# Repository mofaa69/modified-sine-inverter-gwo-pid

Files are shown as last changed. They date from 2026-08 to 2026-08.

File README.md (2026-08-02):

# Metasezgisel Algoritma Tabanlı Modifiye Sinüs Evirici (Inverter) Tasarımı

Bu proje, **TÜBİTAK 2209-A Üniversite Öğrencileri Araştırma Projeleri Destekleme Programı** (Proje No: 1919B012454606) kapsamında **Karadeniz Teknik Üniversitesi Elektrik-Elektronik Mühendisliği Bölümü**'nde tamamlanmış lisans bitirme çalışmasıdır.

---

## 📌 Proje Özeti
Bu çalışmada, 24V DC giriş gerilimini 12V-18V RMS 50Hz AC çıkış gerilimine dönüştüren, 180W maksimum güce sahip kapalı çevrim bir modifiye sinüs evirici sistemi tasarlanmış ve prototipi üretilmiştir. Sistemin güç hatları pcb üzerinde yapılmamış olup 1.5mm çok damarlı kablolar ile hibrit bir şekilde yapılmıştır.PCB üzerinde mikrokontrolcü yuvası tasarımı Attiny85 için yapılmıştır ancak kolaylıkla arduino mikrokontrolcülerle beraber de kullanılabilir.

Çıkış geriliminin kararlılığını sağlamak için Arduino tabanlı bir **PID denetleyici** kurgulanmış; PID kontrolörün Kp ve Ki parametreleri metasezgisel bir sürü zekası algoritması olan **Gri Kurt Optimizasyonu (GWO)** ile optimize edilmiştir.

---

## 🛠️ Donanım & Sistem Mimarisi

* **Güç Katı & Topoloji:** 24V DC beslemeli, 4 adet **IRLZ44N MOSFET** ile kurgulanmış H-Köprüsü (H-Bridge) topolojisi.
* **Sürücü Katı & Bootstrap:** High-side MOSFET tetikleme problemini çözmek amacıyla **IR2110** sürücü entegreleri ve 47µF/25V kondansatör + UF4007 hızlı diyottan oluşan **Bootstrap (Yüzer Kaynak)** mimarisi.
* **Mikrodenetleyici:** Arduino Uno R3 (ATmega328P) — Donanımsal Timer kesmeleri (Timer1 ISR) kullanılarak 50Hz Hassas PWM sinyali üretimi.
* **Geri Besleme & Sensör:** Tam dalga diyot köprüsü (UF4007), $22k\Omega / 4.7k\Omega$ gerilim bölücü ve 10µF filtre kapasitöründen oluşan feedback devresi.
* **Kullanıcı Arayüzü:** I2C modüllü 16x2 LCD ekran ve potansiyometre ile 12V–18V arası anlık referans gerilimi ayarlama.
3d devre
---

## 📊 Simülasyon ve Optimizasyon (GWO)

* **MATLAB / Simulink:** H-Köprüsü güç katı, yük değişimleri ve batarya voltaj düşümü senaryoları altında kapalı çevrim olarak simüle edilmiştir.
* **Gri Kurt Optimizasyonu (GWO):** Simulink modeliyle entegre çalışan MATLAB algoritması sayesinde minimum hata kriterine göre en ideal kontrolör parametreleri tespit edilmiştir.

---

## 📁 Depo İçeriği

* **`/pcb`**: Şematik çizimler, PCB layout ve 3D kart modelleri.
* **`/simülasyon`**: GWO optimizasyon `.m` kodları ve kapalı çevrim Simulink (`.slx`) modeli.
* **`/yazılım`**: Timer kesmeli, I2C ekran destekli ve anlık PI kontrol hesaplamalı C++ / Arduino kodları.
* **`/proje raporu`**: KTÜ Bitirme Projesi nihai raporu (PDF).

---

## 🔬 Laboratuvar & Deneysel Sonuçlar
Fiziksel olarak üretilen baskı devre (PCB) üzerinde yapılan testlerde, 8.2Ω / 4A yük altında 12.00V ve 18.03V True RMS çıkış değerleri elde edilmiş, simülasyon sonuçları ile deneysel verilerin tam uyum sağladığı doğrulanmıştır.

---

## 🛠️ Kullanılan Teknolojiler
`KiCad` | `MATLAB / Simulink` | `Arduino IDE` | `C/C++` | `GWO Algorithm` | `PID Control`

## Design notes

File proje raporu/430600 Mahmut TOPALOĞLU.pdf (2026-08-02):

T.C.

## KARADENİZ TEKNİK ÜNİVERSİTESİ Mühendislik Fakültesi

### Elektrik-ElektronikMühendisliği Bölümü

# Metasezgisel Algoritma Tabanlı Modifiye Sinüs Evirici

### (Bitirme projesi)

### 430600 Mahmut TOPALOĞLU

## Dr. Öğr. Üyesi YAHYA DANAYİYEN

### Mayıs 2026 TRABZON

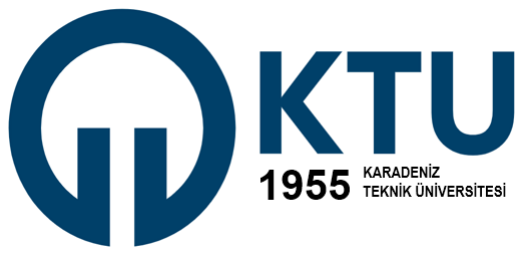
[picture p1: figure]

T.C.

## KARADENİZ TEKNİK ÜNİVERSİTESİ Mühendislik Fakültesi

### Elektrik-ElektronikMühendisliği Bölümü

# Metasezgisel Algoritma Tabanlı Modifiye Sinüs Evirici

### (Bitirme Projesi)

### 430600 Mahmut TOPALOĞLU

## Dr. Öğr. Üyesi YAHYA DANAYİYEN

### Mayıs 2026 TRABZON

i

LİSANS BİTİRME PROJESİ ONAY FORMU

Mahmut TOPALOĞLU tarafından Dr. Öğr. Üyesi Yahya DANAYİYEN yönetiminde

hazırlanan “Metasezgisel Algoritma Tabanlı Modifiye Sinüs Evirici” başlıklı lisans

bitirme projesi tarafımızdan incelenmiş, kapsamı ve niteliği açısından bir Lisans Bitirme

Projesi olarak kabul edilmiştir.

Danışman | : Dr. Öğr. Üyesi Yahya DANAYİYEN
Jüri Üyesi 1 | : Prof. Dr. H. İbrahim OKUMUŞ
Jüri Üyesi 2 | : Dr. Öğr. Üyesi Hakan KAHVECİ
Bölüm Başkanı | : Prof. Dr. AYTEN ATASOY

ii

### ÖNSÖZ

Bitirme çalışmam boyunca hiçbir zaman desteklerini esirgemeyen, bilgi ve tecrübeleriyle bana yol gösteren danışman hocam Sayın Dr. Öğr. Üyesi Yahya

DANAYİYEN başta olmak üzere tüm değerli hocalarıma içten teşekkürlerimi sunarım.

Projeyi hayata geçirirken sundukları imkân ve olanaklar için Karadeniz Teknik Üniversitesi Elektrik-Elektronik Mühendisliği Bölüm Başkanlığı’na şükranlarımı

iletirim. Ayrıca, bu tez çalışması TÜBİTAK Bilim İnsanı Destek Programları

Başkanlığı (BİDEB) tarafından yürütülen 2209-A Üniversite Öğrencileri Araştırma

Projeleri Destekleme Programı kapsamında, 1919B012454606 başvuru numaralı ve

"Metasezgisel Algoritma Tabanlı Modifiye Sinüs Kesintisiz Güç Kaynağı" başlıklı

proje ile desteklenmiştir. Sağladıkları desteklerden dolayı Türkiye Bilimsel ve Teknolojik Araştırma Kurumu’na (TÜBİTAK) teşekkür ederim.

Eğitim ve öğrenim hayatım boyunca her zaman yanımda olan, sevgileri ve destekleriyle

beni daima güçlendiren değerli aileme ise sonsuz şükranlarımı sunarım.

Mahmut Topaloğlu

2026 Trabzon

iii

İÇİNDEKİLER

iv

### 1.8.9. İş Paketi 9 | 11

### 1.8.10. İş Paketi 10 | 11

### 2.TEORİK ALTYAPI | 12

### 2.1. Genel Bilgiler | 12

### 2.1.1 Evirici Devresi Tasarımı | 12

### 2.1.2. PID Kontrolcü Tasarımı | 13

### 2.4. Güç Elektroniği Elemanları | 20

### 3. TASARIM | 19

### 3.1. Genel Bilgiler | 19

### 3.2. Boyutlandırmalar | 19

### 3.3. Sistem Bileşenleri ve Seçimleri.. | 20

### 3.3.1. Batarya | 20

### 3.3.2. MOSFET | 21

### 3.3.3. MOSFET Sürücü Entegresi | 22

### 3.3.4. Bootstrap Devresi.. | 22

### 3.3.5. Arduino Uno R3 | 23

### 3.3.6. Manuel Anahtar | 24

### 3.3.7. Gerilim Sensörü | 24

### 3.3.8. LCD Ekran | 26

### 3.3.9. I2C Modülü | 26

### 3.4. Uygulanan Yöntemler | 27

### 3.5. Yazılımlar | 27

### 3.6. Malzeme Listesi ve Ekonomik Analiz | 27

### 3.7. Hukuki Boyut | 28

v

vi

ÖZET

Bu projede, genel kullanım amaçlı metasezgisel algoritma tabanlı bir modifiye

sinüs evirici tasarımı yapılacaktır. Evirici çıkış gerilimi PID denetleyici ile kontrol

edilecek olup, PID denetleyici parametreleri de metasezgisel algoritmalar ile

belirlenecektir. Bu projede, çıkış gerilimini tasarlayacağımız PID denetleyici ile anlık

olarak kontrol ederek sistemin verimini ve kalitesini artırmayı amaçlıyoruz.

Projede tasarlanacak evirici devresi ve mikrodenetleyici tarafından oluşturulan

PWM sinyalleri aracılığıyla 12V-18V 50Hz modifiye sinüs gerilime çevrilip çıkışa

verilecektir. Bu çevrim işlemi de tasarlayacağımız PID kontrolcü ile denetlenerek çıkış

geriliminin kalitesi artırılacaktır. Cihazın maksimum çıkış gücü 180W olacaktır.

Çıkıştaki gerilimin efektif değeri bir ekran vasıtası ile gözlemlenebilecektir Yük olarak

8.2 ohm ve 4A değerindeki direnç yükü kullanılacaktır.

vii

SEMBOLLER VE KISALTMALAR

KGK: Kesintisiz Güç Kaynağı

PWM: Pulse Width Modulation

PID: Proportional Integral Derivative

ADC: Analog - Digital Converter

ms: Milisaniye

GWO: Grey Wolf Optimization

V: Volt

A: Amper

W: Watt

R: Direnç

C: Kapasite

L: Endüktans

DA: Doğru Akım

AA: Alternatif Akım

Hz: Hertz

USB: Universal Serial Bus

Wh: Watt Saat

Ah: Amper Saat

D: Duty Cycle (Görev Döngüsü)

GND: Ground

LCD: Liquid Crystal Display

I2C: Inter-Integrated Circuit

IEEE: Institute of Electrical and Electronics Engineers

IEC: International Electrotechnical Commission

ISO: International Standards Organization

viii

ŞEKİLLER DİZİNİ

ix

ÇİZELGELER DİZİNİ

### 1. GİRİŞ

### 1.1. Genel Bilgiler

Evirici Nedir, Kullanım Alanları ve Önemi

Evirici, teknik literatürde “Inverter” olarak adlandırılan ve Doğru Akımı (DC)

Alternatif Akıma (AC) dönüştüren bir güç elektroniği devresidir. Elektrik şebekesinin

bulunmadığı veya kesildiği durumlarda; bataryalar, güneş panelleri veya diğer DC

kaynaklardan elde edilen enerji, evlerde ve endüstriyel tesislerde kullanılan şebeke

formatına bu birimler aracılığıyla dönüştürülür. Kesintisiz Güç Kaynaklarının (KGK)

temel işlevi olan enerji yedekleme süreci, bataryadaki gücün kullanılabilir bir forma

sokulmasını sağlayan evirici modülünün performansına doğrudan bağlıdır.

Teknolojik cihazların hassasiyeti ve yenilenebilir enerji kaynaklarına olan yönelim

dünya genelinde arttıkça, verimli enerji dönüşümü sağlayan evirici sistemlerinin önemi

de artış göstermektedir. Kararlı bir alternatif akım arzı, sistem güvenliği açısından

kritik bir parametredir. Bu doğrultuda evirici sistemlerinin önemi ve kullanım alanları

şu şekilde özetlenebilir:

- Enerji Kalitesi ve Cihaz Güvenliği: Eviriciler (özellikle tam sinüs dalga

üreten modeller), şebeke kalitesinde temiz ve dalgalanmasız bir alternatif akım

üreterek hassas elektronik donanımların elektriksel gürültüden veya uygunsuz

dalga formlarından zarar görmesini engeller. Bu durum, cihazların kullanım

ömrünü uzatırken yüksek bakım maliyetlerinin önüne geçer.

- Yenilenebilir Enerji Entegrasyonu: Güneş enerjisi ve rüzgar türbinleri gibi

kaynaklardan elde edilen enerjinin günlük kullanıma uygun hale getirilmesi

veya şebekeye geri basılması ancak yüksek verimli eviriciler aracılığıyla

mümkündür.

- Şebekeden Bağımsız (Off-Grid) Sistemler: Elektrik şebekesinin ulaşamadığı

kırsal bölgelerde, karavanlarda veya acil durum sahalarında kurulan bağımsız

sistemlerde eviriciler, depolanmış enerjiyi kullanılabilir hale getirerek yaşam ve

çalışma sürekliliğini sağlar.

Tüm bu etkenler ve güç elektroniği prensipleri göz önüne alındığında; bu çalışma

kapsamında doğru akımı düşük kayıp ve yüksek verimle alternatif akıma çeviren,

kaliteli ve temiz enerji ihtiyacını karşılayacak bir modifiye sinüs evirici tasarımı

gerçekleştirilmesi hedeflenmiştir.

### 1.2. Literatür Araştırması

Tasarlanacak olan proje için gerekli literatür arştırması yapılmıştır. Proje ile alakalı

olan bazı kaynaklar ve içerikleri aşağıda belirtilmiştir.

BP, yıllık Dünya Enerjisi 2022 İstatistiksel Raporunda, küresel birincil enerji

talebinin 2021 yılında yüzde 5,8 arttığını ve 2019’daki pandemi öncesi seviyelerini

yüzde 1,3 oranında aştığını belirtmiştir. BP’nin yakından izlenen enerji raporuna

göre, 2021’de birincil enerji, tarihin en büyük miktarıyla büyümüştür. [1]. Büyüyen

bu enerji ihtiyacının sağlanabilmesi için çoğunlukla fosil yakıtlar kullanılmıştır [2].

Fosil yakıtların doğaya verdikleri zarar bilindiğinden ve enerjiyi doğaya daha fazla

zarar verilmeden elde etmek istenildiğinden, bu kaliteli ve temiz enerji ihtiyacını

karşılamak için geliştirilen çözümlerden biri güç kaynaklarıdır. Güç kaynakları

mekanik ve elektrikli olarak ikiye ayrılır. Mekanik güç kaynakları gazla benzinle

veya dizel çalışan jeneratörlere denir, bunun yanında rüzgâr yoluyla elde edilen

elektrik enerjisi de bu gruba girer. Elektrikli güç kaynakları ise KGK (Kesintisiz Güç

Kaynakları) yani eviriciler ve güneş enerjisi sistemleridir. Burada bahsedilen kaliteli

enerji ihtiyacını karşılamak için verimliliği daha yüksek olması sebebiyle [3] bir

modifiye sinüs evirici üzerinde durulacaktır.

A. H. Eltom ve A. Demirbas tarafından 2009 yılında Miami, Florida’da

gerçekleştirilen “IEEE International Conference on Electric Machines and Drives

(IEMDC)” konferansında sunmuş oldukları çalışmanın konferans bildirisinde,

naylon endüstrisindeki motor sistemlerinin enerji verimliliği, PWM ve kare dalga

inverterler kullanılarak karşılaştırılmıştır. Deneysel veriler göstermiştir ki, PWM

inverterlerin motor akım harmonikleri %15 oranında azalmış ve motor verimliliği

%10’a kadar artmıştır. Ayrıca, kare dalga inverterlerin daha yüksek harmonik

distorsiyona neden olduğu ve enerji kayıplarını artırdığı tespit edilmiştir. Çalışma,

PWM inverterlerin enerji tasarrufu ve motor performansı açısından daha avantajlı

olduğunu ortaya koymuştur.[4]

S. Nur Dirim 2010 yılında adaptif kontrol sistemleri ve uygulamaları hakkında bir

derleme makale yayımlamıştır. Çalışmasında adaptif kontrol sistemini PID

kontrolcü sistemi ile kıyaslamıştır. Adaptif kontrol sistemi, kontrol ettiği prosesteki

değişimlere göre kendi kontrol parametrelerini otomatik olarak değiştiren sistem olarak tanımlanır ve prosesin çalışma koşullarının ya da çevre koşullarının

değişmesi | sonucunda | kontrol | sistemindeki | ayarlarının | sürekli | olarak

değiştirilmesiyle gerçekleşir [5].

Model Öngörülü Kontrol Sistemi: Model Öngörülü Kontrol, sürecinin gelecekteki

çıkışları hakkında tahminlerde bulunmak için sisteme ait bir modele ihtiyaç duyan bir geri-beslemeli kontrol algoritmasıdır. Öngörü, öngörü ufku olarak adlandırılan

sonlu bir zaman aralığında sisteme ait bir modele dayalı olarak gerçekleştirilir.

Optimizasyon probleminin çözümü, optimal dizinin ilk elemanının sisteme enjekte

edildiği kontrol vektörünü oluşturur. Güncellenen sistem bilgisi kullanılarak bir

sonraki zaman aralığı için problem tekrar çözülür.[6]

Bulanık Mantık (Fuzzy Logic): Bulanık mantık kontrol sistemlerinde belirsiz ve

kesin olmayan bilgilerin temsil edilmesine olanak tanır. Geleneksel kontrol

tekniklerinden farklı olarak, kesin matematiksel modeller yerine dilsel değişkenler,

bulanık kümeler ve dilsel kurallar kullanır. Bu sayede kontrol sistemi, insan benzeri

bir mantıkla karar verebilir ve değişen koşullara uyum sağlayabilir. Fuzzy PID

kontrolcü, üç ana bileşenden oluşur: Bulanık Mantık Kontrolörü (FLC), PID

kontrolcü ve bu iki çıktıyı birleştiren bir harmanlama mekanizması.[7]

Dayanıklı Kontrol Sistemi (Robust Control): Dayanıklı kontrol, bilinmeyen parazit

sinyallerine, belirsiz dinamiklere sahip ve kesin olarak bilinen veya bilinmeyen

parametrelere sahip sistemler için tasarlanan sabit bir kontrolörün sistemdeki tüm

etkilere rağmen sistemi dayanıklı ve kararlı yapmasını sağlamak için kullanılır.[8]

PID Kontrol Sistemi: PID kontrolörü ilk olarak 1939'da piyasaya sürülmüştür ve

günümüze kadar süreç kontrolünde en yaygın kullanılan kontrol mekanizması

olmuştur. 1989 yılında Japonya'da yapılan bir araştırma, süreç endüstrilerinde

kullanılan kontrolörlerin %90'ından [9] fazlasının PID kontrolörleri veya PID

kontrolörlerinin gelişmiş versiyonları olduğunu göstermiştir. PID açılım olarak Proportional-Integral-Derivative yani Oransal-İntegral-Türevsel kontrol anlamına

gelir ve sistemin istenen bir hedef değere (setpoint) ulaşmasını sağlamak için hata

sinyalini (mevcut değer ile hedef değer arasındaki fark) düzenlemek amacıyla üç

bileşeni kullanır. Bunlar Kp, Ki ve Kd parametreleridir.

### 1.3. Özgünlük

Geliştirecek eviricinin en önemli bölümü kullanılacak kontrol tekniğidir. Kontrol

teknikleri temelde 2 ana başlıkta değerlendirilir;

- Açık döngü kontrol sistemleri
- Kapalı döngü kontrol sistemleri

Açık döngü kontrol sistemlerinde sistemin girişine istenilen ayarlamalar yapılır ve

sistem çıkışı denetlenmez. Kapalı döngü kontrol sistemlerinde iste sistem çıkışı belirli

sensörler yardımı ile denetlenir ve giriş verisi, çıkış verisine göre tekrar düzenlenerek

yeni bir çıkış oluşturulur.

Tasarlanacak olan proje kapalı döngü bir sistem olacaktır ve çıkış geriliminin

oluşturulmasında bir PID kontrolcü kullanılacaktır. PID kontrolcünün kontrol

parametreleri ise metasezgisel bir algoritma olan “Gri Kurt Optimizasyon Algoritması”

ile hesaplanacaktır. Sistemde parametrelerin belirlenebilmesi için gri kurt algoritması

kullanılacaktır. Kullanım sebepler ise gri kurt optimizasyon (GWO) algoritması, basit

uygulanabilirliği, hızlı yakınsaması ve üstün yakınsama sonuçları gibi birkaç önemli

avantaja sahiptir. Bu özellikleri, algoritmanın optimizasyon sorunlarını çözmede farklı

alanlarda etkili bir şekilde kullanılmasını sağlamaktadır [10].

Literatür incelendiğinde, tasarlanan evirici çıkışlarında harmoniklerin doğrusal

olmayan yükte %5’ten büyük olduğu, tasarlanan kontrol algoritmalarının karmaşık ve

yüksek işlem yükü gerektirdiği, anahtarlama kayıplarının yüksek olduğu tespit

edilmiştir. Bu problemlerin etkilerini azaltmak için bu çalışmada metasezgisel

optimizasyon algoritması tabanlı PID denetleyici tasarlanarak kare dalga evirici çıkış

gerilimi denetlenecektir. Böylece çıkış geriliminde daha düşük harmonikli gerilim elde

edilecek, optimal kontrol parametreleri sayesinde kontrol sisteminin dayanıklılığı

arttırılacaktır.

### 1.4. Yöntem

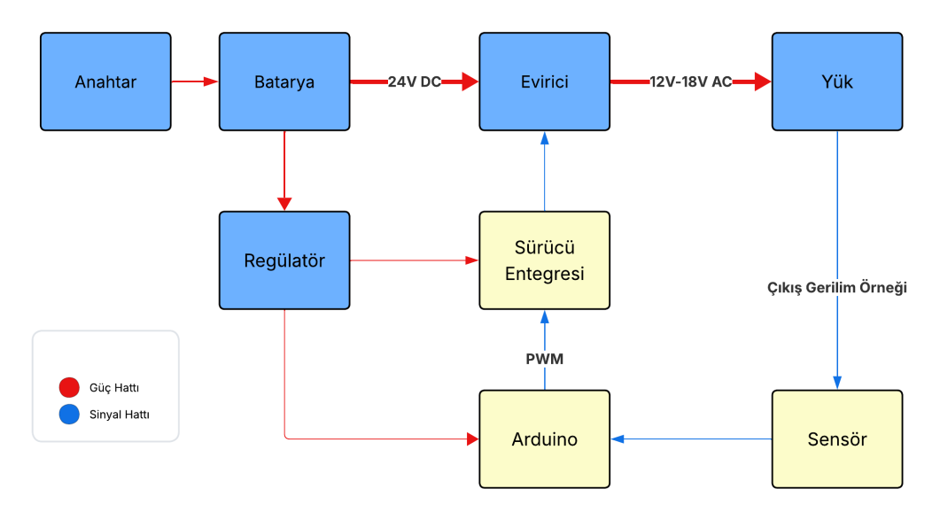
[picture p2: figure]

Şekil 1.1: Sistemin Genel Blok Şeması

Tasarlanacak cihaz, çıkışta düşük harmonikli 12V-18V 50Hz AA gerilim elde

edecek şekilde çalışacak ve bu işlev bir Arduino içerisine kodlanacak PID

kontrolcü ile sağlanacaktır. PID kontrolcünün Kp, Ki ve Kd parametreleri, gri kurt

algoritması kullanılarak optimize edilecektir. Şekil 1’de görülebileceği gibi, cihaz

evirici modu olmak üzere temel bir modda çalışacaktır.

Evirici modunda şarj edilen bataryalar evirici devresini besler ve yüke gerilimi

iletir ve çıkışta 12V-18V 50Hz AA gerilim oluşturulur.

Evirici devresinde dört MOSFET ve iki MOSFET sürücü entegresi yer

alacaktır, bu sürücülere PWM sinyali Arduino tarafından sağlanacaktır. Arduino,

çıkıştan alınan gerilim örneğini işleyerek PID kontrolcü sayesinde yeniden

hesaplayacak ve PWM sinyalini güncelleyerek döngüyü sürdürecektir.

Sistemde maddi kısıtlar nedeniyle trafo kullanılmayacak, ancak istenirse evirici

çıkışına bir trafo eklenerek daha yüksek gerilim seviyelerine ulaşılabilir.

### 1.5. Yaygın Etki

Hedeflenen proje gerçekleştirilerek elde edilen PID kontrolcü destekli modifiye

sinüs evirici tamamlanmış ve günlük kullanımda hizmet verebilecek bir ürün olmasının

yanı sıra geliştirmeye açık bir ürün olacaktır. Bu ürün sayesinde güç kaynakları sektörü

üzerine yönelik yeni ürünler geliştirilmede kullanılabilecek ve ilgili yatırımcılar ile

iletişime geçilip bir start-up firması kurulabilecektir. Böylece sektör için güç

elektroniği dönüştürücüleri üretilebilecektir.

Eviriciler üzerinde çalışabilecek elektrik elektronik mühendisi yetiştirilmiş

olunacaktır. Bunun yanında projenin yeni ve daha gelişmiş algoritma ve devreler ile bu

alanda yeni projeler geliştirecek öğrenciler yetiştirilebilecektir.

### 1.6. Standartlar

Çizelge 1.1 Projede Dikkat Edilmesi Gereken Standartlar
Standart | Açıklaması
ISO 9001:2008 | Kalite Standardı
IEEE 519-2022 | Elektrik Güç Sistemlerinde Harmonik Kontrol İçin IEEE Standardı

### 1.7. Çalışma Takvimi

Çalışma takvimi Çizelge 1.2.’de verilmektedir.

Çizelge 1.2. İş-Zaman Çizelgesi

İP No | İş Paketinin Adı ve Amacı | Kimler Tarafından Çalışıldığı | Zaman Aralığı | Projeye Katkısı
1 | Proje fikrinin bulunması ,literatür araştırması ve özgün değerin belirlenmesi | Mahmut TOPALOĞLU (L) | Ekim 2020 | Hangi konuda proje yapılacağının belirlenmesi, bu ve benzeri konularda yapılan çalışmaların araştırılması ve özgün fikrin belirlenerek proje taslağının oluşturulması.
2 | Uygulanacak yöntemlerin belirlenmesi ve ilgili teorik çalışmaların yapılması. | Mahmut TOPALOĞLU (L) | Ekim-Kasım 2020 | Özgün fikre ulaşmak için yapılan literatür taraması sonrası uygulanacak yöntemlerin ve devre topolojilerinin belirlenmesi.
3 | Belirlenen topolojilere göre sistem tasarımı oluşturulmaya başlanması ile bütçe planlaması ve mevzuat araştırması. | Mahmut TOPALOĞLU (L) | Kasım-Aralık 2020 | Sistemin çalışma şemasının ve devrelerde kullanılacak elemanların tamamiyle belirlenip simülasyona geçişe hazırlık ve maddi kısıtların belirlenmesi.
4 | Simülasyonların yapılması, sonuçların değerlendirilmesi ve Mühendislik Tasarımı kitabının yazılması. | Mahmut TOPALOĞLU (L) | Aralık 2020 -Ocak 2021 | Tasarlanan sistemin simülasyon modeli oluşturulup, paket programlar veya geliştirilecek yazılımlarla simülasyonu yapılır. Simülasyon prototipin çalışıp çalışmayacağının önceden bilkinmesini sağlayacağından önemlidir.
5 | Final sınavları ve Mühendislik Tasarımı sunumlarının yapılması. | Mahmut TOPALOĞLU (L) | Ocak 2021 | Hazırlanan Mühendislik Tasarımı jüri tarafından sunumlar sırasında değerlendirilir. Mühendislik Tasarımı Bitirme Projesinin ön koşulu olduğundan sunumları başarıyla tamamlamak önemlidir.

Çizelge 1.2. İş-Zaman Çizelgesi (Devam)

İP No | İş Paketinin Adı ve Amacı | Kimler Tarafından Çalışıldığı | Zaman Aralığı | Projeye Katkısı
6 | Evirici devre tasarımının gerçeklenmesi, bir PWM sinyali oluşturularak MOSFET sürücüleri kontrol edebilmek. | Mahmut TOPALOĞLU (L) | Ocak-Şubat 2021 | Evirici devreyi oluşturmak ve herhangi bir PWM sinyali oluşturarak MOSFET’leri kontrol edebilmek.
7 | PID kontrolcü tasarımı, gri kurt algotritmasının PID entegrasyonu ve testi. | Mahmut TOPALOĞLU (L) | Şubat-Mart-Nisan 2021 | PID kontrolcünün Arduino içine kodlanması ve Kp, Ki ve Kd değerlerini belirlenen metasezgisel algoritma ile belirlemek ve test etmek.
8 | Projenin test edilmesi, verilerin değerlendirilmesi ve dış kabin montajı | Mahmut TOPALOĞLU (L) | Mart Mayıs 2021 | Projenin tüm parçalarının birleştirilmesi, son testlerin gerçekleştirilmesi ve dış kabinin oluşturulup bu kabine montajın yapılması.
9 | Bitirme Projesi kitabının yazılıp teslim edilmesi. | Mahmut TOPALOĞLU (L) | Mayıs-Haziran 2021 | Yapılan tüm çalışmaların detaylı şekilde anlatan, fikir aşamasından montaja kadar geçen tüm aşamaları içeren bitirme projesi kitabının uygun formatta hazırlanıp tesliminin yapılması.
10 | Final sınavları, Bitirme Projesi Sergisi ve sunumlarının yapılıp projenin bitirilmesi. | Mahmut TOPALOĞLU (L) | Haziran 2021 | Hazırlanan projenin bitirme projesi sergisinde çalışır durumda segilenmesi ve jürinin projeyi değerlendirmesi.

Çizelge 1.3. Risk analizi ve B planları

İP No | Projeye Katkısı | Risk Analizi
1 | Hangi konuda proje yapılacağının belirlenmesi, bu ve benzeri konularda yapılan çalışmaların araştırılması ve özgün fikrin belirlenerek proje taslağının oluşturulması. | Yapılan ön çalışmanın tekrarının yapılması veya konunun değiştirilmesi
2 | Özgün fikre ulaşmak için yapılan literatür taraması sonrası uygulanacak yöntemlerin ve devre topolojilerinin belirlenmesi. | Belirlenen yöntem veya topolojilerin istenilen değerleri vermemesi durumunda yeni yöntm veya topolojilerin araştırılması.
4 | Tasarlanan sistemin simülasyon modeli oluşturulup, paket programlar veya geliştirilecek yazılımlarla simülasyonu yapılır. Simülasyon prototipin çalışıp çalışmayacağının önceden bilkinmesini sağlayacağından önemlidir. | Simüle edilen devre modelinin eleman değerlerinin gerçekte var olmaması durumuna karşın yeniden simülasyon çalışması yapılır.
6 | Evirici devreyi oluşturmak ve herhangi bir PWM sinyali oluşturarak MOSFET’leri kontrol edebilmek. | Devre elemanlarının hatalı çalışması durumunda yeni devre elemanları siparişi verilmesi.
7 | PID kontrolcünün Arduino içine kodlanması ve Kp, Ki ve Kd değerlerini belirlenen metasezgisel algoritma ile belirlemek ve test etmek. | Karınca Kolonisi,Parçacık sürü optimizasyonu gibi diğer metasezsigel algoritmalarla tekrar parametrelerin belirlenmesi.
8 | Projenin tüm parçalarının birleştirilmesi, son testlerin gerçekleştirilmesi ve dış kabinin oluşturulup bu kabine montajın yapılması. | Bu iş paketinde bir aksama beklenmemektedir. Ancak gerektiğinde bölümdeki teknik personelden destek alınabilir.

### 1.8. İş Paketleri Organizasyonu ve Çalışma Yönetimi

Bu | projedeki | tüm | iş | paketleri | Mahmut | TOPALOĞLU | tarafından
gerçekleştirilecektir.

### 1.8.1. İş Paketi 1

Projenin hangi alanda olacağını bulabilmek için ilgi alanlarının taranması ve istenilen alanda bir konu belirlenerek literatür taraması yapılıp özgün değer oluşturulması ardından bir taslak oluşturulması.

### 1.8.2. İş Paketi 2

Yapılan araştırmalar sonucu belirlenen özgün değeri uygulayabilecek yöntemlerin araştırılması ve gerekli devre topolojilerinin incelenip tasarıma başlanması

### 1.8.3. İş Paketi 3

Tasarım oluştuktan sonra sistemin çalışma şemasının ve devrelerde kullanılacak elemanların tamamıyla belirlenip simülasyona geçişe hazırlık ve maddi kısıtların belirlenmesi.

### 1.8.4. İş Paketi 4

Paket programlar ile tasarlanan sistemin, piyasadaki devre elemanları değerlerine yakın elemanlar kullanılarak bir simülasyonu oluşturulur. Simülasyon yardımı ile prototipin çalışma karakteristiği hakkında bilgi edinilir ve istenilen değerler elde edildikten sonra tasarım aşaması son bulur.

### 1.8.5. İş Paketi 5

Yazılan mühendislik tasarım kitabının teslimi sonrası etkili şekilde sunumu yapılır ve değerlendirilir.

### 1.8.6. İş Paketi 6

Öncelikle MOSFET, MOSFET sürücü ve Arduino bağlantıları yapılır ve MOSFET’leri sürecek bir PWM sinyali oluşturularak MOSFET’lerin doğru çalıştığından emin olunur. Tüm devre elemanlarının testi tamamlanınca belirlenen devre topolojisine göre bir evirici devre oluşturulur ve ilk testler yapılır.

### 1.8.7. İş Paketi 7

Sistemi kontrol edecek olan Arduino içerisine PID kontrolcü kodlaması yapılır ve bu PID kontrolcünün kontrol parametreleri olan Kp, Ki ve Kd değerlerini gri kurt optimizasyon algoritması ile hesaplayıp kontrolcüye entegre edilir.

### 1.8.8. İş Paketi 8

PID kontrolcü ile evirici devresi birleştirilir ve denemeler yapılır, sistemin beklenen şekilde çalıştığı gözlemlendikten sonra diğer tüm parçalar birleştirilir ve dış kabin hazırlanarak sistemin tüm parçaları bu kabine montajlanarak cihaz tamamlanmış olur.

### 1.8.9. İş Paketi 9

Yapılan tüm çalışmaların detaylı şekilde anlatan, fikir aşamasından montaja kadar geçen tüm aşamaları içeren bitirme projesi kitabının uygun formatta hazırlanıp tesliminin yapılması.

### 1.8.10. İş Paketi 10

Hazırlanan projenin bitirme projesi sergisinde çalışır durumda sergilenmesi ve jürinin projeyi değerlendirmesi.

### 2. TEORİK ALTYAPI

### 2.1. Genel Bilgiler

Eviricinin oluşturulması için ilk etapta kullanılacağı alana uygun, istenilen enerji

ihtiyacını belirli bir süre karşılayabilecek batarya seçilecektir. Bu doğrultuda

belirlenen süre tam yük altında bir saat olacaktır. Mikrodenetleyici, PID kontrolcünün

vereceği geribildirime göre PWM sinyali üretecek ve sonuç olarak bataryadan alınan

gerilimi 12V-18V 50Hz AA gerilime (şebeke gerilim değeri) dönüştürecek. DA/AA

eviricinin ve PID kontrolcünün tasarımı ve gerekli parçaları temin edildikten sonra

devrenin montajı gerçekleştirilecektir. Tasarlanacak sistem, 2 temel gruptan

oluşacaktır.

### 1. Evirici Devresi

### 2. PID Kontrolcü

### 2.1.1. Evirici Devresi Tasarımı

Tek fazlı tam dalga modifiye sinüs evirici devre topolojisi olarak H-Köprüsü kullanılacaktır şeması Şekil 2’de gösterilmiştir. İki adet akünün seri bağlanmasıyla

elde edilen 26V DA gerilim evirici girişine bağlanacaktır. Tasarımda 4 adet

MOSFET kullanılacaktır. Her 2 MOSFET 1 MOSFET sürücü ile sürülecektir.

MOSFET’lere iletilecek 2 adet pwm sinyali olacaktır. MOSFET’lerin açılıp

kapanacağı anahtarlama frekansı şebeke geriliminin frekansı ile aynı olacak şekilde

50Hz olacaktır. MOSFET’lere anahtarlama yapacak PWM sinyalleri PID

kontrolcünün verisine bağlı olarak Arduino ile üretilecektir. PID kontrolcünün

burada yapacağı işlem gelen veriye göre oluşturulacak olan pwm sinyalinin duty

cycle değerini belirlemek olacaktır. Duty cycle değeri modifiye sinüs eviricilerde

değiştirildiği takdirde gerilimin şekli sinüs şekline dönüşeceği için evirici sonrası

çıkış geriliminin etkin değerini 12V değerinde tutabilmek adına giriş gerilimini

24V seçerek duty cycle değerini değiştirme imkânı sağlanacaktır. Devre Matlab

Simulink uygulaması üzerinde simüle edilmiştir. Sistem çıkışında elde edilen

gerilim bir LCD ekrana yazdırılacaktır. Bu ekran Arduino pinlerinden tasarruf

etmek amacıyla I2C modülü ile Arduino’ya bağlanacaktır.

MOSFET'ler Gate Drive (Kapı Sürücü) yöntemi ile tetiklenecektir. Gate Drive

yöntemi, MOSFET'lerin gate bacağına uygun gerilim uygulayarak açılmalarını ve

kapanmalarını sağlar. Bu yöntem, düşük voltajlı sinyalleri yüksek voltajlara

dönüştürerek MOSFET'leri tetikler. Bu yöntem için geri beslemeli kontrolle

referans değişimi karşısında uygun duty cycle değeri PID denetleyici ile

ayarlanacaktır.

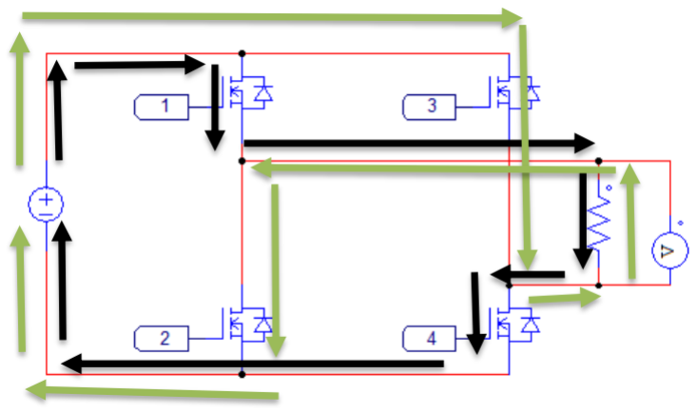
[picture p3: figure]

Şekil 2.1: H-Köprüsü Devre Topolojisi

### 2.1.2. PID Kontrolcü Tasarımı

PID kontrolcü (Oransal-İntegral-Türev), bir sistemin istenen referans değerine

ulaşmasını sağlayan, yaygın olarak kullanılan bir kontrol algoritmasıdır. Bu

kontrolcü, sistemdeki hatayı (istenen değerden sapmayı) sürekli izleyerek, hatayı

minimuma indirmek için üç temel bileşeni kullanır:

Oransal (P): Hatanın anlık değeriyle orantılı bir tepki üretir. Hata büyüdükçe,

kontrolcüden gelen düzeltici sinyal de orantılı olarak artar.
İntegral (I): Geçmişte birikmiş hataları göz önünde bulundurarak sistemdeki

uzun süreli sapmaları düzeltir. Bu bileşen, sistemde süregelen bir kaymayı yok

etmek için gerekli müdahaleyi sağlar.

Türev (D): Hatanın değişim hızını ölçerek ani değişikliklere karşı sistemin

daha hızlı tepki vermesine yardımcı olur ve aşırı sapmaların önlenmesini sağlar.[8]

Bu üç bileşen birlikte çalışarak, sistemin hızlı, kararlı ve doğru bir şekilde

hedef değere ulaşmasını sağlar. PID kontrolcü, endüstriyel otomasyon, robotik, ısı

kontrolü ve elektrik motorları gibi birçok alanda yaygın olarak kullanılmaktadır.

Tasarlanacak sistemde PID kontrolcü kullanılmasının amacı çıkış gerilimini

oluşabilecek değişikliklere karşı sürekli sabit değerde tutmaya çalışmak için

olacaktır. PID kontrolcünün genel yapısı Şekil 3’deki şemada gösterilmiştir. PID

kontrolcünün genel parametre formülleri (2.4) - (2.6)

Çıkışta elde edilmek istenen gerilim yani referans gerilimi yine çıkıştan gerilim

sensörü yardımı ile anlık olarak ölçülerek başka bir geri besleme gerilimiyle

beraber PID kontrolcüye girecek ve PID kontrolcü gerekli hesaplamaları yaparak

bir çıkış sinyali üretecektir ardından bu ürettiği sinyali eviriciye ileterek AA

gerilimin oluşması sağlanacaktır. Süreç kendini sürekli aynı döngüde tekrar ederek

sistem çıkışını dengede tutacak ve çıkış gerilimindeki hata en aza indirilecektir.

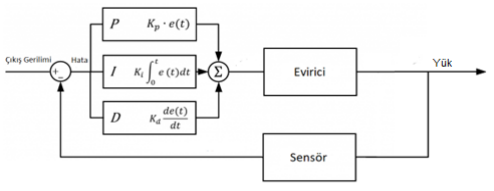
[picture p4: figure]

Şekil 2.2: PID Kontrolcü Şeması

u(t) = Kp ∗ e(t) + Ki ∗ ∫ e(t)dt

t

0

+ Kd ∗

de(t)
dt

(2.4)
u(t) = Elde edilecek gerilim

(2.5)
e(t) = Hata

(2.6)

Kp parametresi: Bu terim, mevcut hata değerine (setpoint ile süreç değeri

arasındaki fark) orantılı bir kontrol çıkışı üretir. Hata büyükse, kontrol çıktısı da

büyük olur. Ancak sadece orantılı kontrol kullanmak, sistemin bir denge noktasına

ulaşamamasına neden olabilir çünkü sistem sürekli bir hata ile karşılaşabilir

Ki parametresi: Bu terim, geçmiş hata değerlerini toplar ve zamanla entegre

eder. Eğer orantılı kontrol uygulandıktan sonra bir hata kalıyorsa, integral terimi bu

kalıntı hatayı ortadan kaldırmaya çalışır. Hata yok olduğunda, integral terimi

büyümeyi durdurur. Bu sayede, orantılı etkiler azalırken, integral etkisi artar

Kd parametresi: Bu terim, hatanın gelecekteki eğilimini tahmin etmek için

mevcut hata değişim oranını kullanır. Derivatif kontrol, hata değişim hızına bağlı

olarak bir kontrol etkisi sağlar. Hata değişim hızı ne kadar hızlıysa, kontrol etkisi

de o kadar büyük olur

Kp,Ki ve Kd değerlerinin artışının çıkış grafiği üzerindeki etkilerin gösterimi

Çizelge 2.1’dekigibidir.

Çizelge 2.1. Denetleyici Kontrol Parametreleri Tablosu

Denetleyici | Yükselme Zamanı | Aşma | Yatışma Zamanı | Kalıcı Durum Hatası (s-s error)
Kp | Kısalır | Artar | Az Değişir | Azalır
Ki | Kısalır | Artar | Artar | Ortadan Kalkar
Kd | Az Değişir | Azalır | Azalır | Az Değişir

Çizelge 2.1’de görülen Kp, Ki, Kd parametrelerinin düzgün seçilmesi çok

önemlidir. Bu seçimi yapabilmek için çeşitli metasezgisel algoritmalar geliştirilmiş

ve kullanılmıştır. Bunlardan bazıları karınca kolonisi, parçacık sürü optimizasyonu,

yapay balık sürüsü ve gri kurt algoritmalarıdır [10]. Sistemde parametrelerin

belirlenebilmesi için gri kurt algoritması kullanılacaktır. Kullanım sebepler ise gri

kurt optimizasyon (GWO) algoritması, basit uygulanabilirliği, hızlı yakınsaması ve

üstün yakınsama sonuçları gibi birkaç önemli avantaja sahiptir. Bu özellikleri,

algoritmanın optimizasyon sorunlarını çözmede farklı alanlarda etkili bir şekilde

kullanılmasını sağlamaktadır [11].

Gri kurt algoritması, 2014 yılında geliştirilmiş bir metasezgisel stokastik sürü

zekâsı algoritmasıdır. Bu fikir gri kurtların avlanmasından esinlenilmiş ve ortaya

çıkarılmıştır. Sürü içerisinde ortalama 5 ila 12 kurt vardır ayrıca alfa, beta, delta ve

omega olmak üzere 4 türleri vardır. Alfa sürünün en yetkili olan ve ağırlığı en fazla

olan kurttur, kararları vererek sürüyü yönetir. Alfa kurttan sora ona itaat eden ve

diğer kurtların üzerinde ağırlık sahibi olan kurtlar ise beta ve delta kurtlardır. Sürü

hiyerarşisinde en altta bulunan kurt ise omega kurttur bu kurtlar diğer tüm baskın

kurtlara itaat ederler.

Kurtların hiyerarşisinin matematiksel modelinde, alfa(α) kurtlar sürünün

lideridir ve emirleri diğer kurtlar tarafından yerine getirilmesi gereklidir. Beta(β)

kurtlar, karar süresince alfaya kararda yardımcı olan kurtlardır ve alfa kurt olmak

için en iyi adaylar bunlardır. Delta(δ) kurtlar, hem alfaya hemde betaya itaat etmek

zorundadır ancak hiyerarşide 3. Sıradadırlar. Omega(ω) kurtlar sürü hiyerarşisinin

en altında yer alan sürünün en ezik kurtlarıdır. Tüm kurtların omegalar üzerinde

hakimiyet kurarlar. Sürünün günah keçileri ve en önemsiz bireyleridir. Sürüde en

son yemek yemelerine izin verilir.Alfa en uygun çözüm olarak değerlendirilir. İkinci ve üçüncü sırada ise sırasıyla beta ve deltadır. Geri kalan tüm çözümler ise

omegadır. Alfa, beta ve deltaya diğer kurtlar tarafından yaklaşılacağı varsayılır.

Her yaklaşımda alfa beta ve deltanın hangi kurt olduğu yeniden belirlenir ve kurtlar

yeniden rütbelendirilir. Bu düzenleme kurtlar en kısa mesafede saldırı için en

uygun yerlerde sürü halinde bulunana kadar devam eder.[11].

Gri kurtların avlanma mekanizmasının matematiksel modeli üç ana aşamadan

oluşur:

- Avın izlenmesi, takip edilmesi ve yaklaşılması.
- Avın durması için peşinden koşma, kuşatma ve rahatsız edilmesi.
- Nihayetinde avın saldırıya uğraması.

Gri kurtların avlarının etrafını sarması matematiksel olarak (2.7) numaralı

denklemler ile ifade edilir.

D⃗ = |C · Xp

⃗ (t) − X (t)| ,

(2.7)

X (t + 1) = Xp

⃗ (t) − A · D⃗ ,

Burada t, mevcut yinelemeyi gösterir; A ve C katsayı vektörleridir. Xp

⃗ avın

konum vektörüdür ise X gri kurdun konum vektörüdür. Katsayı vektörleri A ve C

vektörleri aşağıdaki gibi hesaplanır:

A = 2a · r⃗1 − a ,

(2.8)

C = 2 · r⃗2 ,

Burada a′nın bileşenleri, yinelemeler boyunca 2'den 0'a doğru lineer bir şekilde

azaltılır ve r1 ile r2, [0,1] aralığında rastgele vektörlerdir.

Avlanma süreci genellikle α ve β tarafından yönlendirilir, δ ise ara sıra katılır.

En iyi aday çözümler yani α, β ve δ avın potansiyel konumu hakkında daha iyi

bilgiye sahiptir. Diğer arama ajanları (ω) ise, üç en iyi arama ajanının konumlarına

göre pozisyonlarını günceller. Bu güncelleme süreci matematiksel olarak aşağıdaki

denklemler ile ifade edilir [11].

Dα

⃗ = |C1

⃗ · Xα

⃗⃗⃗⃗ − X | ,

Dβ

⃗⃗⃗⃗ = |C2

⃗ · Xβ

⃗ − X | ,

(2.9)

Dδ

⃗⃗⃗ = |C3

⃗ · Xδ

⃗ − X | ,

X1

⃗ = Xα

⃗⃗⃗⃗ − A1

⃗ · (Dα

⃗ ) ,

X2

⃗ = Xβ

⃗ − A2

⃗ · (Dβ

⃗⃗⃗⃗ ) ,

(2.10)

X3

⃗ = Xδ

⃗ − A3

⃗ · (Dδ

⃗⃗⃗ ) ,

X (t + 1) =

X1

⃗ (t) + X2

⃗ (t) + X3

⃗ (t)
3

(2.11)

Avın yaklaşımını matematiksel olarak modellemek için α değerini azaltırız.

A ’nın dalgalanma aralığı da α ile azaltılır. A , [-α, α] aralığında rastgele bir

değerdir ve α, iterasyonlar boyunca 2'den 0'a doğru lineer olarak azalır. A ’nın

rastgele değerleri [−1,1] aralığında olduğunda, bir arama ajanının bir sonraki

konumu, mevcut konumu ile avın konumu arasında herhangi bir yerde olabilir. ∣A ∣

< 1 koşulu, kurtları avı saldırmaya zorlar. Saldırının ardından, bir sonraki

yinelemede tekrar avı aramaya devam ederler; bu aşamada kurtlar arasında en iyi

çözüm olan α tekrar bulunur. Bu işlem, sonlandırma kriteri karşılanana kadar

tekrarlanır.

Özet olarak bizim α, β ve δ değerlerimiz av bittiği zaman kesinleşmiş ve Kp,

Ki ve Kd değerleri olarak kontrolcünün parametreleri olacaklardır [12]. Yapılan

benzetim çalışmasında Kp, Ki ve Kd değerleri sırasıyla 2.3, 0.5, 0.02 olarak

bulunmuştur.

### 3. TASARIM

### 3.1. Genel Bilgiler

Yapılacak çalışmada sistemin enerjilendirilmesi 2 adet kuru akü vasıtası ile

yapılacaktır. Sistemin daha düzgün bir görüntüsü olması adına bir kabin içerisine

yerleştirilecektir. Sistemin çıkışındaki gerilimin istenilen değerde kalabilmesi için

kapalı çevrim bir PID kontrolcü kullanılacak ve bu kontrolcünün parametreleri

metasezgisel optimizasyon algoritmaları ile belirlenecektir. Sistem çıkışında elde

edilen gerilim değeri bir potansiyometre ile istenilen seviyede ayarlanabilecek ve bu

değer ekrana yansıtılacaktır.

### 3.2. Boyutlandırmalar

Sistemin kabini yerel esnaftan alınan eski bir evirici kutusudur. Görselleri Şekil

4’deki gibidir.

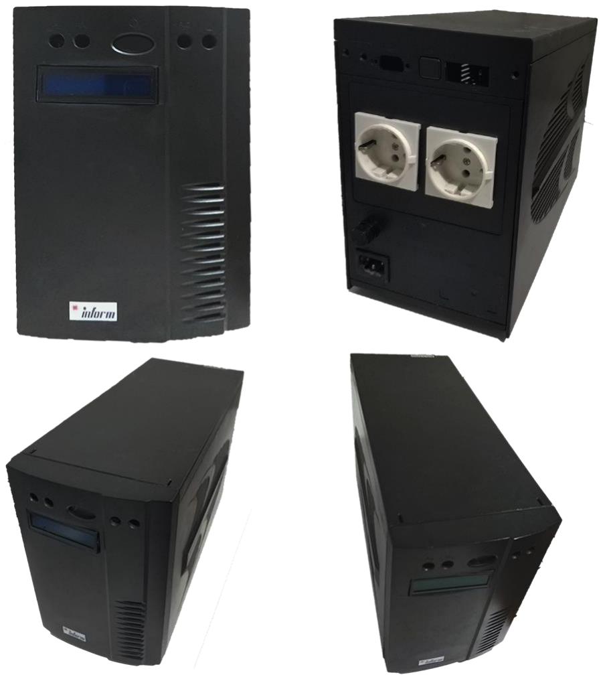
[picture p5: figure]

Şekil 3.1: Kabin

### 3.3. Sistem Bileşenleri ve Seçimleri

### 3.3.1 Batarya

Bataryanın kullanılacak olan diğer elemanlarla doğrudan çalışabilecek bir

batarya olması gereklidir. Bu durumda bir tanesi 13V olacak olan ve seri bağlı

şekilde evirici devresine 26V civarı gerilim verecektir.

Kullanılacak bataryanın türü yapılan araştırmalar sonucunda Kurşun-Asit

teknolojisine sahip bir batarya olacaktır. Kullanılacak batarya Şekil 5’ de

gösterilmiştir. Bu tipte bir bataryanın avantajları şunlardır.

- Uygun maliyet
- Kolay temin
- Hızlı şarj edilebilme
- Dayanıklı oluşu
- Kendi kendine deşarjda, şarj edilebilir pil sistemlerinin en düşükleri

arasındadır (ayda yaklaşık %2)

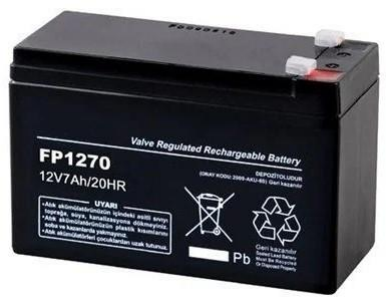
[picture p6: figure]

Şekil 3.2: Kurşun Asit Akü

Bu doğrultuda, 12V/7A kurşun-asit aküler, kullanım için en uygun model

olarak belirlenmiştir. Cihazın tam güçle 45 dakika süreyle çalışabilmesi amacıyla

yapılan hesaplamalar (2.1)-(2.3) denklemlerinde detaylandırılmıştır. Hesaplamalar

sonucunda, cihazın belirtilen çalışma süresini karşılamak için N = 2 adet akü

kullanılması gerektiği tespit edilmiştir. Bu hesaplamalarda, yükün tükettiği güç

Po(W) , yedekleme süresi T(saat) , cihazın toplam enerji ihtiyacı E(Wℎ) , akü

gerilimi Vakü(V), akü kapasitesi C(Aℎ), akü akımı Iakü(A), akü sayısı N (adet)

değerlerini ifade eder.

E = Po × T

E = 180 × 0.75 = 135Wℎ

(2.1)

C =

E

Vakü

=

135
12 = 11.25Aℎ

(2.2)

N =

C

Iakü

=

11.25
7

= 1.6 ≈ 2 adet

(2.3)

Denklemlerden de görülebileceği gibi 1 Adet 24V batarya ile bir saat çalışma

süresi elde edilir ancak kullanılacak bataryalar 12V olduğu için 2 adet ve seri bağlı

şekilde kullanılacaktır.

### 3.3.2. MOSFET

MOSFET, elektrik akımını kontrol eden bir güç elektroniği anahtarlama elemanıdır. Üç terminali vardır: Gate (G), Source (S) ve Drain (D). Gate'e uygulanan

voltaj, Source ile Drain arasındaki akımın geçip geçmeyeceğini belirler. Gate'e yeterli

voltaj uygulandığında, akım Source'dan Drain'e akar, yani MOSFET açılır. Eğer voltaj

yoksa, akım geçmez ve MOSFET kapanır. Bu özellik, MOSFET'leri güç elektroniği

uygulamalarında, özellikle devrelerdeki akımı anahtarlamak ve güç kontrolü yapmak

için ideal hale getirir. Bu projede tercih edilen IRLZ44N MOSFETin iletim dirençleri

küçük olduğu için anahtarlama kayıpları düşüktür. Bu sepele bu çalışmada tercih

edilmişlerdir. Kullanılacak modelin görseli Şekil 6’daki gibidir.

Şekil 3.3: IRLZ44N MOSFET

### 3.3.3. MOSFET Sürücü Entegresi

Tasarlanan H-Köprüsü invertör devresinde, mikrodenetleyiciden alınan 5V

seviyesindeki mantıksal PWM sinyalleri, güç MOSFET'lerini doğrudan sürmek için

hem gerilim hem de akım kapasitesi açısından yetersizdir. Güç MOSFET'lerinin

tam iletime geçebilmesi ve anahtarlama kayıplarının en aza indirilmesi için Gate-

Source terminalleri arasında daha yüksek bir gerilime ve Gate kapasitansını

mikrosaniyeler içinde şarj/deşarj edebilecek yüksek tepe akımlarına ihtiyaç vardır.

Bu gereksinimleri karşılamak amacıyla donanım tasarımında IR2110 MOSFET

sürücü entegresi kullanılmıştır. Bu sürücü; lojik seviyedeki sinyalleri güç

seviyesine yükseltmesinin yanı sıra, H-Köprüsü topolojisindeki en büyük

zorluklardan biri olan üst kol (High-Side) MOSFET'lerinin sürülmesi problemini

'Bootstrap' mimarisi ile çözmektedir. Tek bir entegre içerisinde hem High-Side hem

de Low-Side sürme yeteneği barındırması. Devrede kullanılan sürücü entegrenin

bağlantı yapısı Şekil 7’de gösterilmiştir.

Şekil 3.4: IR2110 MOSFET Sürücü

### 3.3.4. Bootstrap Devresi

H-Köprüsü topolojisinde kullanılan N-Kanal IRLZ44N, bir "Logic-Level"

MOSFET olup teorik olarak 5V tetikleme sinyaliyle iletime geçebilmektedir. Ancak

yüksek akım çekilen durumlarda Drain-Source arası iç direncini (RDS(on)
) mutlak

minimuma indirmek ve kullanılan IR2110 sürücü entegresinin Düşük Voltaj Koruması

sınırlarına takılmamak amacıyla, Gate-Source terminalleri arasına optimum değer olan

12V tetikleme gerilimi uygulanması tasarlanmıştır.

Devrenin üst kolunda (High-Side) bulunan MOSFET iletime geçtiğinde, Source

bacağındaki gerilim doğrudan sistemin giriş besleme gerilimi olan 24V seviyesine

yükselmektedir. Bu fiziksel koşulda üst kol MOSFET'inin kapanmasını engellemek ve o 12V'luk farkı korumak için Gate bacağına toprağa (GND) göre sistem beslemesinin

12V üzerinde ( VDC + 12V), yani mutlak olarak 36V seviyesinde bir gerilim

uygulanması zorunludur.

Sistemde bu seviyede ikinci bir yüksek voltaj kaynağı bulunmadığından, IR2110

sürücüsünün 'Bootstrap (Yüzer Kaynak)' donanım mimarisi kullanılmıştır. Devreye

eklenen harici diyot ve kondansatör sayesinde, alt kol MOSFET'i iletimdeyken kondansatör 12V sürücü beslemesi üzerinden şarj edilmektedir. Üst kol tetikleneceği

an, şarj olmuş bu kondansatör Source bacağındaki yüksek gerilimin üzerine eklenerek

ihtiyaç duyulan 12V'luk (VGS ) farkını anlık olarak sağlar ve MOSFET'in güvenli

şekilde anahtarlanmasını garanti eder. Kullanılan kapasitörün 47µF/25V seçilmesinin

sebebi, 50 Hz frekanstaki 10 ms'lik uzun iletim süresi boyunca Gate voltajının

düşmesini engellemek ve güvenlik sınırında kalmaktır; kullanılan diyotun UF4007

model seçilmesinin sebebi ise ultra hızlı (75 ns) yalıtıma geçerek oluşan 36V yüksek

gerilimin 12V sürücü hattına geri kaçmasını kesin olarak engellemektir. Tasarlanan

devrenin 3B ve PCB tasarımı Şekil 8’de gösterilmiştir.

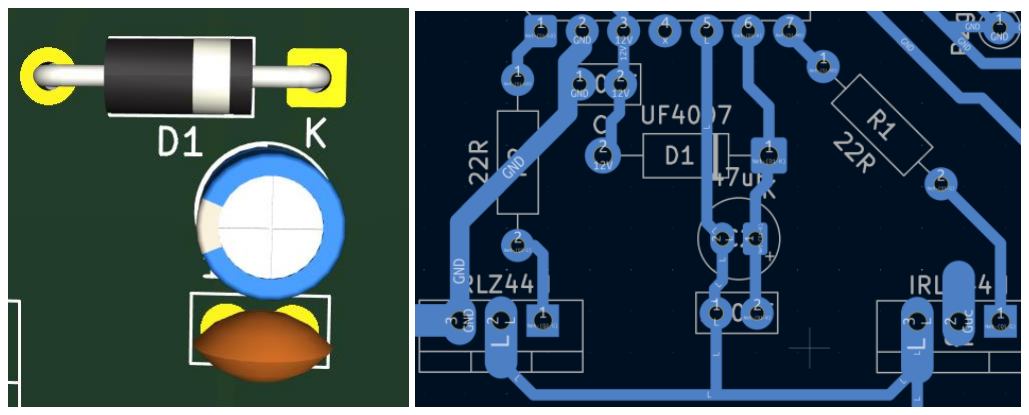
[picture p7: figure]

Şekil 3.5: Bootstrap Devresi

### 3.3.5. Arduino Uno R3

Arduino Uno R3, ATmega328P mikrodenetleyicisiyle çalışan, açık kaynaklı bir

geliştirme kartıdır. Projelerde, özellikle MOSFET sürücüleri ve inverter devrelerini

kontrol etmek için kullanılabilir. 14 dijital giriş/çıkış pini ve 6 analog giriş pini ile

sensörler ve diğer cihazlarla iletişim kurabilir. 5V ile çalışan bu kart, USB üzerinden

programlanabilir ve seri iletişim yapabilir. PWM çıkışı sayesinde PWM kontrolü

gerektiren uygulamalarda kullanılabilir. Kontrol algoritmasının gerçek zamanlı

gösterimi için Arduino UNO, yüksek hız, geniş I/O, kolay programlama ve düşük maliyet gibi avantajları nedeniyle tercih edilmiştir. Kullanılacak olan Arduino moddeli

Şekil 9’de gösterilmiştir.

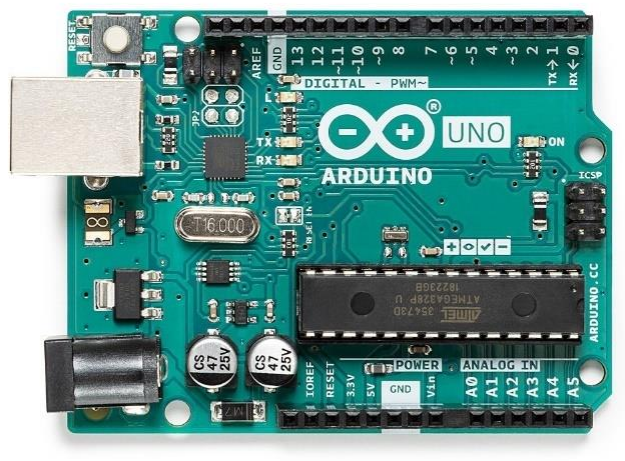
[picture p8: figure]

Şekil 3.6: Arduino Uno R3

### 3.3.6. Manuel Anahtar

Cihazdaki belirli kısımların korumasını artırmak amacıyla 10A akım değerine

dayanabilecek sağlamlıkta manuel anahtar seçilecektir. Kullanılacak elemanın temsili

görseli Şekil 10’da verilmiştir.

Şekil 3.7: Manuel anahtar

### 3.3.7. Gerilim Sensörü

Sistemin çıkışında 26V tepe gerilimi anahtarlanarak 12V-18V RMS aralığına

dönüştürülecektir. Bu dönüştürme işlemini Arduino'dan doğru şekilde okuyabilmek ve

gerekli sinyali sağlıklı şekilde üretebilmek için bir tam dalga doğrultucu ve ardından

gelen gerilim bölücü devre kullanılmıştır.

Tam dalga doğrultucuda halihazırda elimizde bulunan UF4007 diyotlar kullanılmış;

gerilim bölücüde ise iki direnç ve bir kapasitör kullanılmıştır. Bu gerilim bölücüde dirençlerin görevi, üzerlerinden akan akımın direnç değerleri oranında bir gerilim

düşümüne uğramasını sağlayarak yüksek giriş voltajını mikrodenetleyicinin ölçüm

sınırlarına indirgemektir. Kapasitör ise kesikli olan gerilimi absorbe ederek çıkışta stabil

bir DC seviyesi sağlamak için kullanılmıştır.

Kullanılan kapasitör değeri 10uF olarak belirlenmiştir. Bu miktar, DC sinyal

sabitlemede sıklıkla tercih edilen 1-10uF aralığındaki genel standartlara uygundur. Bu

sınırların üzerinde bir kapasitör seçildiği durumda daha iyi bir filtreleme yapılır ancak

kondansatörün şarj-deşarj süreleri uzayacağından sistemde gecikme meydana gelebilir.

Dirençlerin değerleri ise aşağıdaki formül ile hesaplanmıştır:

Vçıkış = Vgiriş ×

Ralt

Rüst + Ralt

(2.12)

26V ×

4.7K
22K + 4.7K

= 4.57V

(2.13)

Seçilen direnç değerleri ile elde edilen çıkış gerilimi, maksimum giriş gerilimi olan

26V değerinde 4.57V olarak alınacak; bu da Arduino'nun ADC pinindeki maksimum

5V gerilim sınırına çok yakın, aynı zamanda güvenli bir değer olarak hesaplanmıştır. Bu

sayede Arduino hem yüksek çözünürlüklü bir okuma yapacak hem de en yüksek gerilim

değeri okunduğu takdirde bile güvenle çalışabilecektir. Devre görseli Şekil 11’deki

gibidir.

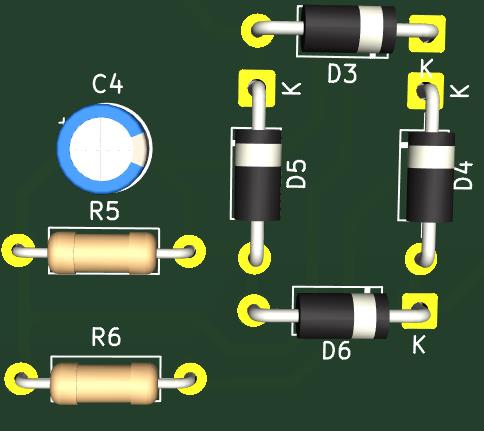
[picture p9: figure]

Şekil 3.8: Gerilim Sensörü

### 3.3.8. LCD Ekran

16x2 LCD ekranlar, projelerde veri görüntülemek için kullanılan, 16 sütun ve 2

satırdan oluşan metin tabanlı ekranlardır. Enerji izleme sistemleri, ölçüm cihazları ve

kullanıcı arayüzü gerektiren uygulamalarda sıkça tercih edilir. Kullanım kolaylığı ve

geniş veri alanı sunması sayesinde projelere esneklik kazandırır. Çoğunlukla 16 pinli bir

bağlantı yapısına sahiptir ve paralel veri iletişimi ile çalışır. Bu bağlantı yapısında güç

pinleri, kontrol pinleri ve veri iletim pinleri bulunur. Bu çalışmada çıkış gerilimini

görüntülemek için kullanılacaktır. Kullanılacak olan model Şekil 12’de gösterilmiştir.

Şekil 3.9: 16x2 LCD Ekran

### 3.3.9. I2C Modülü

Şekil 11’de gösterilen I2C Modülü, mikrodenetleyiciler ile cihazlar arasında

iletişimi kolaylaştıran bir arayüzdür ve özellikle LCD ekranlar gibi çoklu pin bağlantısı

gerektiren cihazlar için pratik bir çözüm sunar. I2C protokolü, yalnızca iki pin (SCL ve

SDA) kullanarak veri iletişimi sağlar; Bu yapı birden fazla cihazın aynı iletişim hattını

paylaşmasına imkan verir. I2C modülü, LCD ekranlara bağlandığında, geleneksel

paralel bağlantıya göre daha az kablo ve daha basit bir devre tasarımı gerektirir.

Böylece, mikrodenetleyicilerdeki giriş-çıkış pinleri diğer işlevler için serbest bırakılır.

Yaygın olarak tercih edilmesinin sebebi projelerdeki kablo karmaşasını azatması ve

montaj süreçlerini hızlandırmasından dolayıdır. Kullanılacak olan model Şekil 13’de

gösterilmiştir.

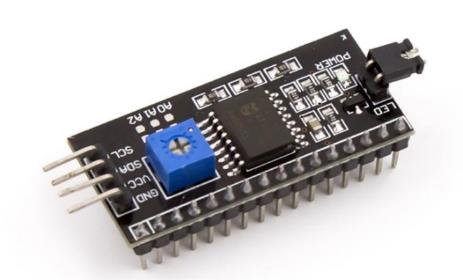
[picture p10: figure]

Şekil 3.10: I2C modülü

### 3.4. Uygulanan Yöntemler

Çalışmadaki kapalı döngü evirici devresi tasarımları MATLAB uygulaması ile

yapılmıştır. Eviricinin performansının iyileştirilebilmesi için kullanılan PID

kontrolcünün parametreleri gri kurt optimizasyonu ile belirlenmiştir. Sistemin kapalı

çevrim olabilmesi için gerekli olan sinyal tasarlanan bir gerilim sensörü ile

mikrokontrolcüye iletilecek ve gerilim oluşturulacaktır. Oluşturulan bu gerilimin

değeri bir potansiyometre yardımı ile 12V-18V arasında değiştirilebilecektir. Çıkış

geriliminin yaklaşık değeri LCD ekranda gösterilecektir.

### 3.5. Yazılımlar

Çalışmada kullanılacak olan Arduino Uno Arduino IDE ile programlanmaktadır.

Simülasyon tasarımları için MATLAB Simulink kullanılmıştır. Devrenin şema çizimi

ve PCB tasarımları için KiCad kullanılmıştır.

### 3.6. Malzeme Listesi ve Ekonomik Analiz

Çizelge 3.1. Malzeme Listesi

Malzemenin adı | Kullanım amacı | Birim fiyatı (TL) | Adedi | Fiyatı (TL)
Arduino Uno R3 | Cihaz yönetimi için. | 320 | 1 | 320
Batarya | Enerji ihtiyacı için. | 500 | 2 | 1000
MOSFET | DA gerilimini AA gerilimine evirmek için. | 25 | 4 | 100
Sürücü Entegresi | MOSFET’leri sürmek için. | 45 | 2 | 90
Çeşitli Devre Elemanı | Cihaz içerisinde kullanılacak kablolar, jaklar, dirençler vs çeşitli alt elemanlar. | 1000 | 1 | 1000
I2C Modülü | LCD ekranı çalıştırmak için. | 30 | 1 | 30

Çizelge 3.1. Malzeme Listesi (Devam)

LCD Ekran | Sistem çıkışını gözlemlemek için. | 250 | 1 | 250
Anahtar | Manuel anahtarlama yapmak için. | 50 | 3 | 50
Potansiyometre | Çıkış gerilimini değiştirmek için | 60 | 1 | 60
Dış Kasa | Cihazı her türlü dış darbeden korumak ve bir arada tutmak için. | 0 | 1 | 0
TOPLAM | | | | 2900

### 3.7. Hukuki Boyut

Üzerinde çalışılan projeye benzer birçok proje tabii ki olmuştur. Bu çalışmanın

ayırt edici tarafı olan PID kontrol mekanizması tarafımızca düşünülmüş ve

tasarlanmıştır. Proje tasarım aşamasındayken yapılan araştırmaların tamamında

kaynak gösterilerek alıntılama yapılmış ve telif haklarına riayet edilmiştir. Projenin

uygulaması yapılırken de oluşabilecek olası değişiklik durumlarında yine telif hakları

gözetilerek uygulama yapılacaktır.

### 4. SİMÜLASYON ÇALIŞMALARI

### 4.1. Genel Bilgiler

Yapılacak proje 2 ana simülasyon aşamasından oluşmaktadır. Matlab

simülasyonunda evirici ve PID kontrol kısımları. Simülasyon çalışmaları yapılırken

ilk önce H-Köprüsü topolojisinde bir evirici devre tasarlanmış ve istenilen değerler

verilerek evirici devrenin normal şekilde çalışabildiği görülmüştür. Bu işlem bittikten

sonra kontrol mekanizmamız olan PID kontrolcünün tasarım aşamasına geçilmiş ve

simüle edilmiştir ardından iki bölüm birleştirilerek çıkış grafikleri ölçülmüş ve

sonuçlandırılmıştır. Sonrasında KiCad simülasyonunda tasarlanan sistemin şeması

çizilmiş ve ardından bu çizilen şemaya uygun olarak PCB tasarımı yapılmıştır.

### 4.2. Simülasyon Yazılımı

MATLAB: Çok paradigmalı sayısal hesaplama yazılımı ve dördüncü nesil

programlama dildir. Sahipli bir programlama dili olan MATLAB, MathWorks

tarafından geliştirilmiştir. MATLAB kullanıcıya, matris işleme, fonksiyon ve veri

çizme, algoritma uygulama, kullanıcı arayüzü oluşturma, C, C++, Java ve Fortran gibi

diğer dillerde yazılmış programlarla ara bağlama imkânı tanımaktadır.

Simulink: Çok alanlı dinamik sistemleri modellemek, simüle etmek ve analiz

etmek için MATLAB tabanlı bir grafik programlama ortamıdır. Birincil arayüzü, bir

grafik blok diyagram aracı ve özelleştirilebilir bir blok kitaplıkları setidir. MATLAB

ortamının geri kalanıyla sıkı entegrasyon sunar ve MATLAB’ı çalıştırabilir veya

ondan komut dosyası yazılabilir. Simulink otomatik kontrol, model tabanlı yazılım ve

dijital sinyal işleme de yaygın olarak kullanılmaktadır. Çalışmada evirici ve PID

kontrolcü simülasyonu için kullanılacaktır.

KiCad: Elektronik devre şemaları ve baskılı devre kartı (PCB) tasarımı için

geliştirilmiş, açık kaynak kodlu ve ücretsiz bir EDA (Elektronik Tasarım

Otomasyonu) yazılımıdır. Şema tasarımı (Schematic Editor) ve PCB çizimi (PCB

Editor) başta olmak üzere, bir projeyi tasarımdan üretim aşamasına getirecek temel

araçları bünyesinde barındırır. KiCad; dahili SPICE simülatörü, 3 boyutlu kart

görüntüleyicisi ve geniş komponent kütüphanesiyle hem hobi kullanıcıları hem de

profesyonel mühendisler tarafından yaygın olarak tercih edilmektedir. Çalışmada PCB

tasarımı, devre şeması çizimi ve 3B modellemesi için kullanılacaktır.

### 4.2.1. Matlab Simülasyonu

Sistem simülasyon çalışmalarına ilk önce birinci kısım olan evirici devre

simülasyonundan başlanmıştır. Evirici devre verilen DA gerilimini mosfetler yardımı

ile istenilen frekansta çevrilmesi ile çalışır. 4 adet MOSFET 2 adet sinyal ile

çalıştırılır. 1 ve 4 numaralı MOSFET’ler simülasyon içerisinde A olarak

adlandırdığımız sinyal ile 2 ve 3 numaralı MOSFET’ler ise B olarak adlandırdığımız

sinyal ile çalışır. Bu iki sinyal birbirinin tersi sinyallerdir ve aralarında 180 derece faz

farkı vardır yani lojik olarak 1-4 MOSFET’leri lojik 1 iken, 2-3 MOSFET’leri lojik 0

değerindedir ve aynı şekilde tersi de geçerlidir. Bu durumda devrede akım iki yönde akar. İlk durum olan 1-4 MOSFET’lerinin çalıştığı durumda yük pozitif bir gerilim ile

beslenir ardından ikinci durum olan 2-3 MOSFET’leri açılır ve yük negatif kutbundan

beslenir. Bunların sonucunda DA gerilimi AA gerilime çevrilmiş olur. PID kontrolcü

ise Mosfet sürücülerin mosfetleri sürebilmesi için gerekli olan PWM sinyalini kapalı

bir döngü içerisinde üretmeye yarar. Tasarlanan simulink devresi Şekil 14’deki

gibidir.

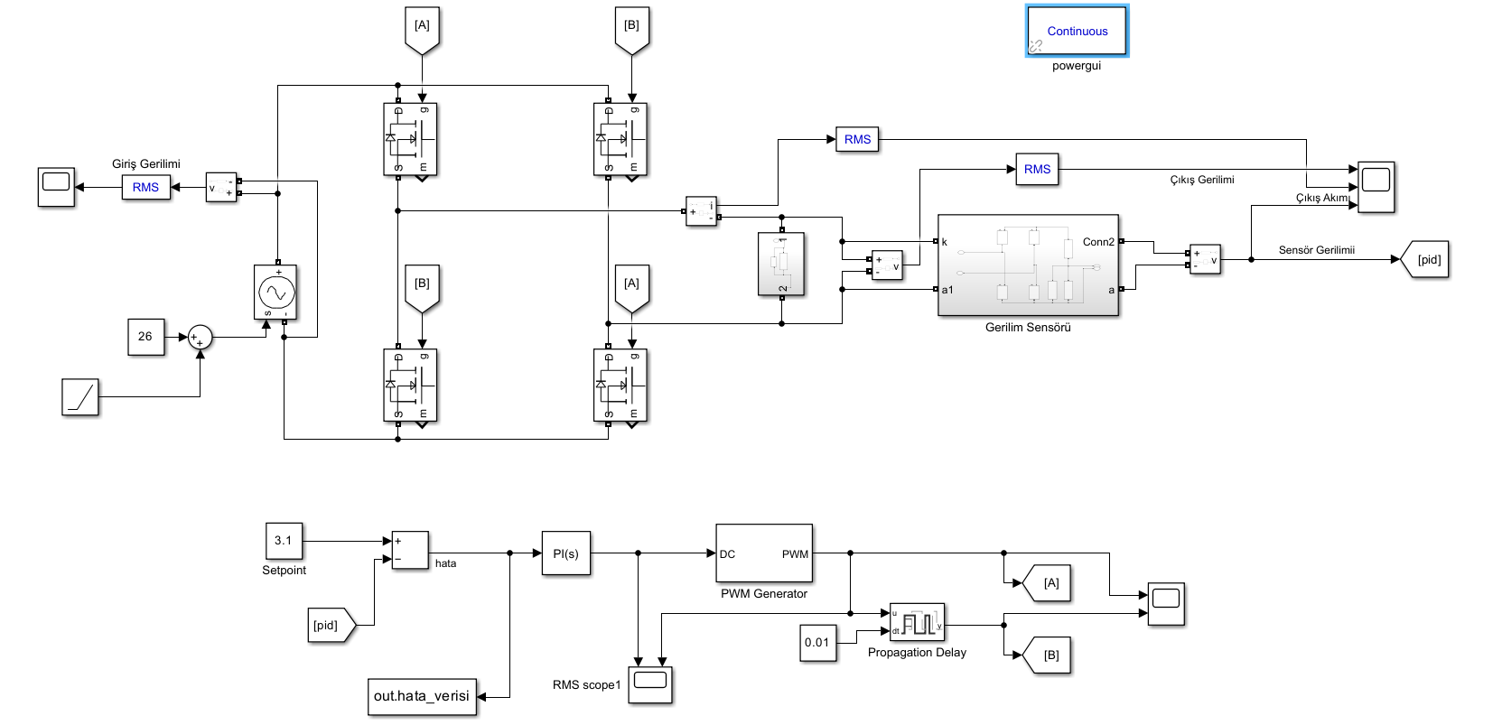
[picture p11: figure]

Şekil 4.1: Kapalı Çevrim Evirici ve PI Kontrolcü Devresi

Belirtilen devre modelinde sistem Matlab Simulink üzerinde kurulduktan sonra PI

kontrolcü için gri kurt optimzasyon algoritması ile birçok sayıda deneme yapılarak

optimal Kp ve Ki değerleri belirlenmeye çalışılmıştır. Kullanılan optimizasyon

algoritmasının kodu Şekil 15’deki gibidir.

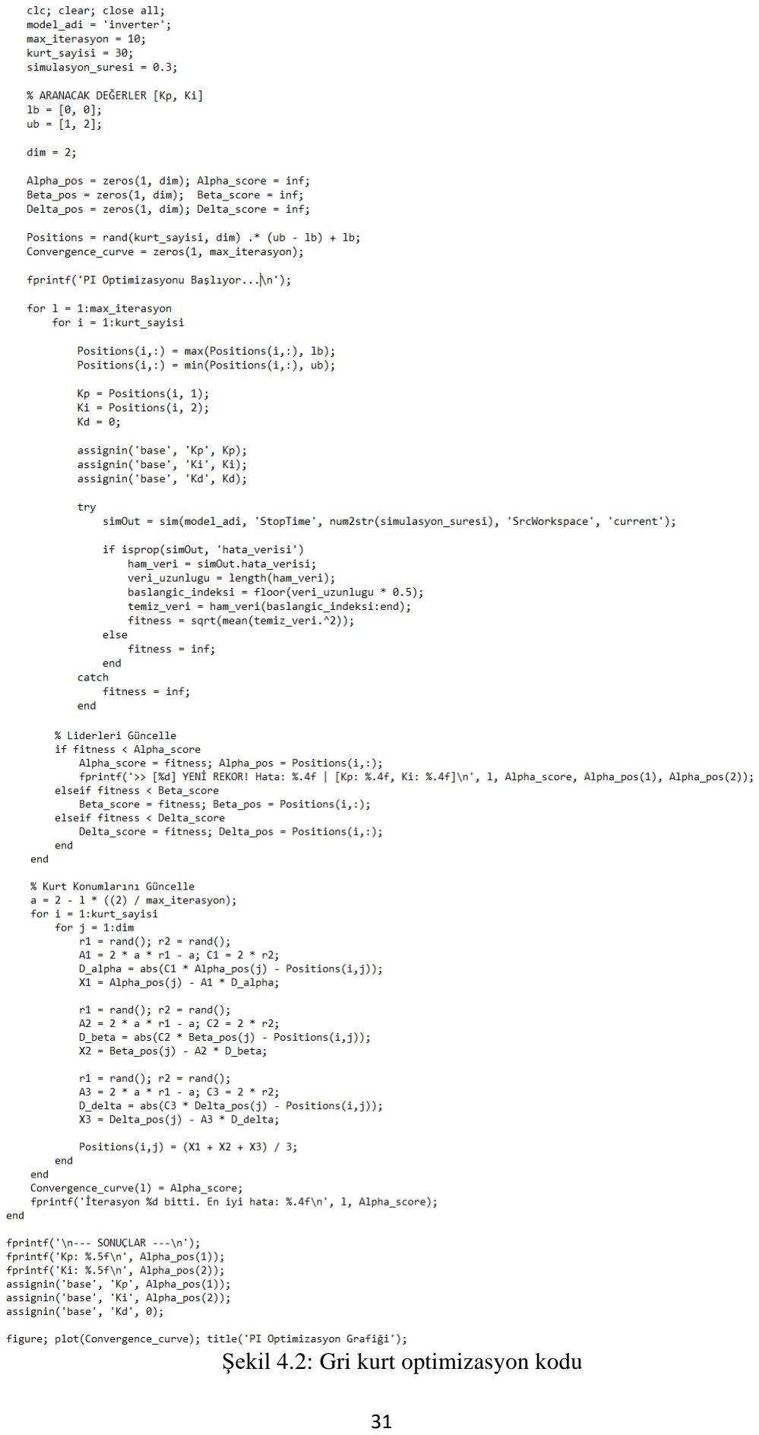
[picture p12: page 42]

Şekil 4.2: Gri kurt optimizasyon kodu

Kullanılan kod ile çeşitli denemeler yapılarak belirli bir değer aralığı belirlenmiş

ve daha hassas sonuç için el ile sürece devam edilerek son değerler Ki=1.9, Kp=0.06

olarak alınmıştır.

### 4.2.2 KiCad Simülasyonu

Sistemin gerçeklenmesi için devre tasarımı KiCad üzerinden yapılmıştır bu

tasarım 2 bölümden oluşmaktadır. Şema çizimi ve PCB tasarımı. Şema çiziminde daha

önceden belirlenmiş topolojiye uygun şekilde sistem tasarımı yapılmıştır. Sistemin

düşük güç ve daha kısıtlı elemanlarla çalışabilmesi için Attiny85 şemaya eklenmiştir.

Gerçeklenirken bu pinlerin yerine aynı işi yapan Arduino pinleri eklenecektir. Çizim

Şekil 16’daki gibidir.

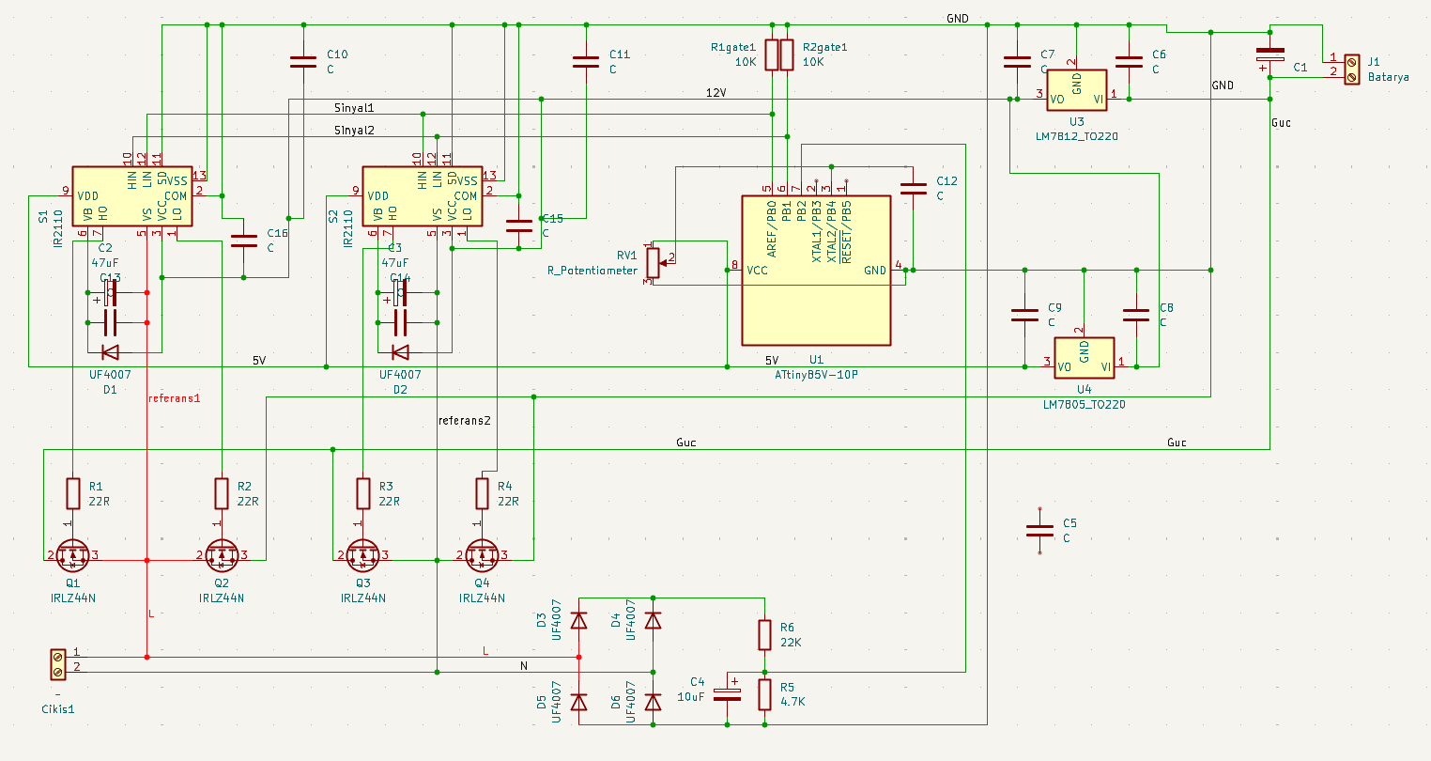
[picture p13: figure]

Şekil 4.3: Sistemin Detaylı Devre Şeması

PCB Tasarımı kısmında sistemin çıkışta sağlaması gereken akım göz önüne

alındığı zaman çıkışta kullanılacak bakır yollar çok geniş olacağı için bunlar PCB

üzerine çizilmemiş olup kartın üzerinden 1.5mm^2 çok damarlı kablolarla bağlantıları

yapılmıştır. Bu doğrultuda sadece sistemin düşük güç hatları PCB üzerine çizilmiştir.

Bu çizimin bir bakır plaka üzerine baskısı yapılacağı göz önüne alınarak kullanılan

bakır yol genişliği 0.07mm değerinde tutulmuştur bu değerin altına nadiren inilmiştir.

Yollar arası en düşük açıklık ise 0.05mm olarak seçilmiştir. Bu açıklık değerinin ütü

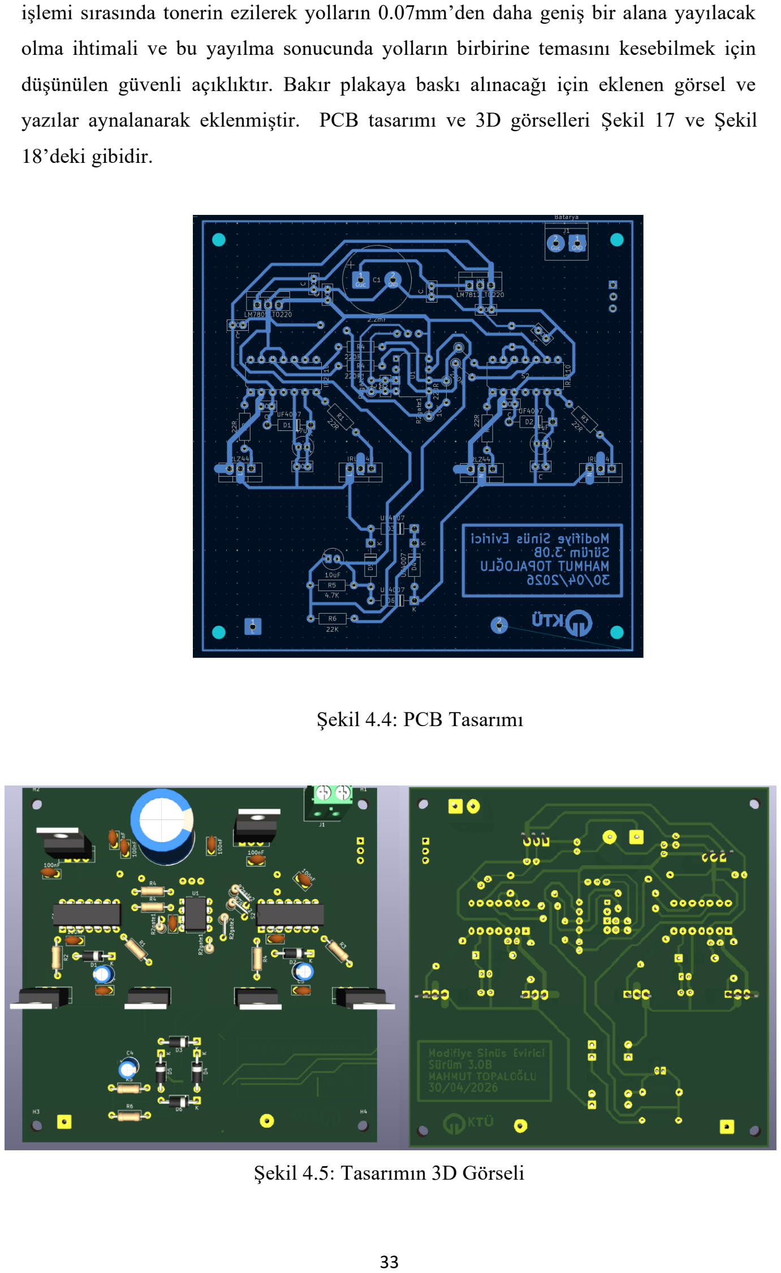
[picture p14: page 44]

işlemi sırasında tonerin ezilerek yolların 0.07mm’den daha geniş bir alana yayılacak

olma ihtimali ve bu yayılma sonucunda yolların birbirine temasını kesebilmek için

düşünülen güvenli açıklıktır. Bakır plakaya baskı alınacağı için eklenen görsel ve

yazılar aynalanarak eklenmiştir. PCB tasarımı ve 3D görselleri Şekil 17 ve Şekil

18’deki gibidir.

Şekil 4.4: PCB Tasarımı

Şekil 4.5: Tasarımın 3D Görseli

### 5. DENEYSEL ÇALIŞMALAR

### 5.1. Devre Baskısı

Baskı devre kartı (PCB) üretimi için öncelikle hazırlanan tasarım, kuşe kağıda 1:1

ölçekte basılmıştır. Tonerin yüzeye daha iyi tutunabilmesi amacıyla, devrenin

sığabileceği boyutlardaki bakır plaka, sabunlu su eşliğinde 200 kum zımpara ile

temizlenmiş; böylece yüzeyde kılcal çizikler oluşturularak yapışma mukavemeti

artırılmıştır. Ardından, ütü vasıtasıyla 3-4 dakika boyunca sıcak baskı uygulanarak

tonerin bakır plakaya tamamen geçmesi sağlanmıştır.

Bu işlemin takibinde, plaka ılık sabunlu su içerisinde kağıt çözününceye kadar

yaklaşık 15-20 dakika bekletilmiş ve kağıt tabakası parmak içiyle hafifçe ovularak

soyulmuştur. Kurulanan plaka; 3 birim tuz ruhu ve 1 birim perhidrol karışımından

oluşan asit çözeltisine bırakılarak açıkta kalan bakır alanlar çözdürülmüştür. Son

aşamada, bakır yollar üzerinde kalan toner tabakası su altında zımparalanarak

temizlenmiş ve baskı devre elde edilmiştir. Elde edilen baskı devre Şekil 19’daki

gibidir.

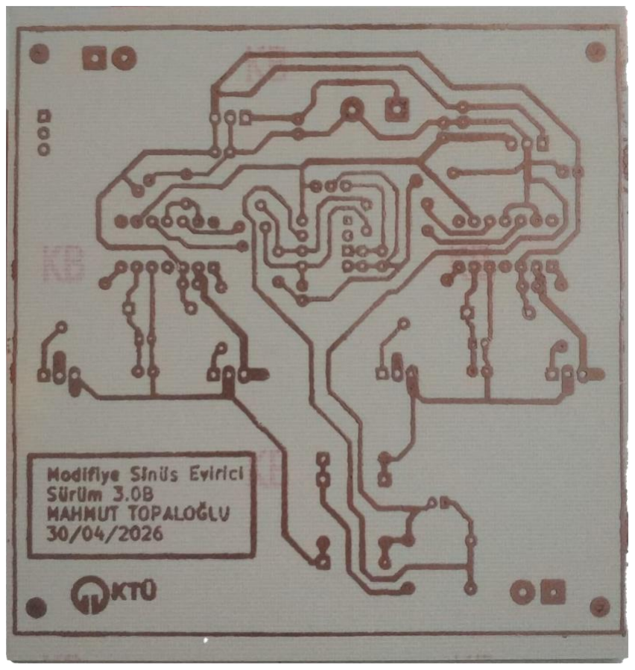
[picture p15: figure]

Şekil 5.1: Dizginin Yapıldığı Baskı Devre

### 5.2. Devrenin Oluşturulması

Bakır plaka üzerine komponent bacakları için uygun çapta bir matkap ucu ile

delikler açıldıktan sonra tüm devre elemanları lehimlenmiştir. Devrenin son hali Şekil

20’deki gibidir.

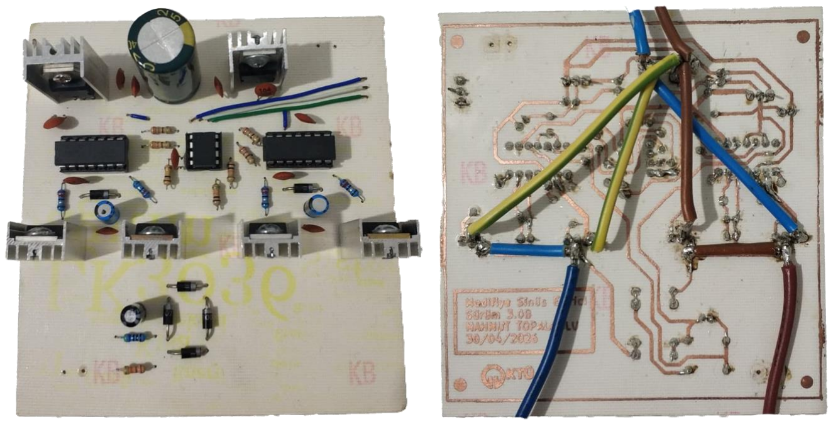
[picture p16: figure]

Şekil 5.2: Sistemin Bağlantılarının Tamamlanmış Modeli

### 5.3. Arduino kodları

Sistemin beyni olan Arduino sensörden aldığı gerilimi bir ADC ye aktarır ve

haritalama yaparak dönüştürür ardından bir PWM sinyali oluşturur. Bu sinyalin görev

döngüsü (duty cycle) değeri daha önce bahsedilen bu değere göre içerisindeki PID

kodları sayesinde hesaplanır ve oluşturulur. Çıkışta okunan gerilimi benzer şekilde

simüle edebilmek adına sensörün değerini 12V ile 18V değerleri arasına yeni bir

haritalandırma yaparak ekrana yansıtır. Çıkış değerini istenilen değer aralığına

getirebilmek için ise bir adet potansiyometre kullanılır. Kodlar Şekil 21’deki gibidir.

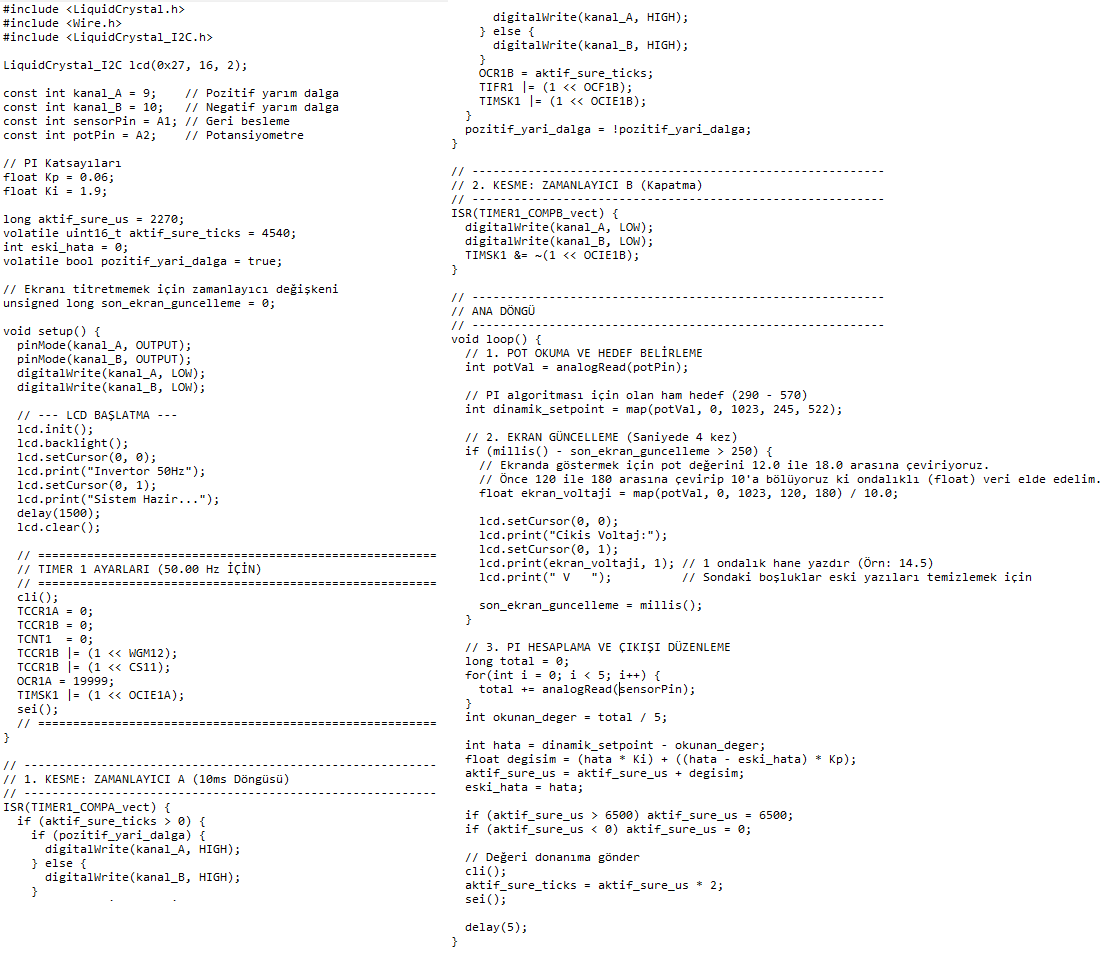
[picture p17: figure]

Şekil 5.3: Kullanılan Arduino Kodları

### 6. SONUÇLAR

### 6.1. Genel Açıklamalar

Yapılacak proje için planlanan çalışmalar başarı şekilde son bulmuştur. Kapalı

döngü bir kontrol sistemi kurulmuş ve evirici çıkışındaki gerilim 12V-18V değerleri

arasında değiştirilebilir şekilde tasarlanmış ve uygulanmıştır ve sabit 50Hz değerine

ulaşmıştır. PID kontrolcünün bu gerilim değerini sabit tutabildiğini ölçebilmek adına

yük değeri değiştirilerek çıkış gerilimindeki değişimler gözlemlenmiş ve sorunsuz

şekilde gerilim değerleri korunmuştur. Proje başarı ile son bulmuştur.

### 6.2. Simülasyon Sonuçları

Simulink üzerinde elde edilen bu değerler ile denemeler yapıldığında istenilen

sonuçlar elde edilmiştir. Sistemin performansını daha doğru şekilde test edebilmek

adına farklı zamanlarda devreye giren yükler ve sürekli azalan bir batarya giriş

gerilimi de simülasyona eklenmiş ve tüm bunlarla beraber sistem test edildiğinde

sistemin simülasyon tarafında tam olarak istenilen şekilde çalıştığı onaylanmıştır.

Sistemin 12V ve 18V çıkış grafikleri Şekil 22 ve Şekil 23’te verilmiştir.

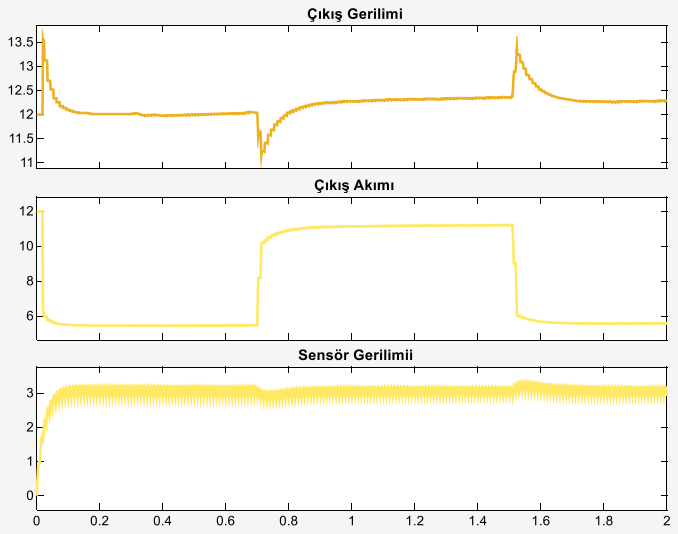
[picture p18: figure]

Şekil 6.1: 12V Çıkış Simülasyon Grafiği

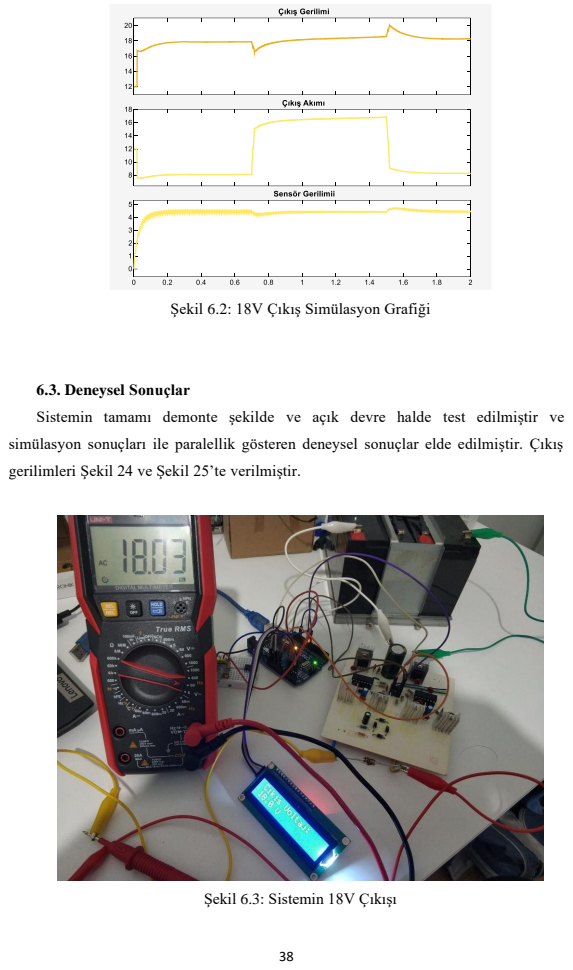
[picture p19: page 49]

Şekil 6.2: 18V Çıkış Simülasyon Grafiği

6.3. Deneysel Sonuçlar
Sistemin tamamı demonte şekilde ve açık devre halde test edilmiştir ve
simülasyon sonuçları ile paralellik gösteren deneysel sonuçlar elde edilmiştir. Çıkış
gerilimleri Şekil 24 ve Şekil 25’te verilmiştir.

Şekil 6.3: Sistemin 18V Çıkışı

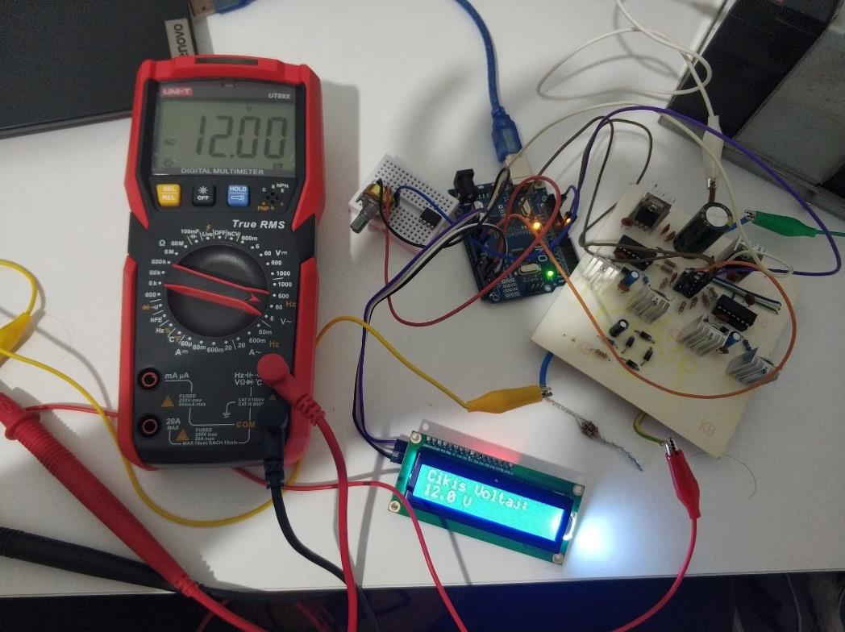
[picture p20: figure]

Şekil 6.4: Sistemin 12V Çıkışı

### 7. DEĞERLENDİRME

Bu projede güç elektroniği elemanları ve kontrol sistemleri üzerine araştırmalar

yapıldı ve açık, kapalı döngü kontrol sistemleri, metasezgisel optimizasyon

algoritmaları ve bunların hesaplanıp sistemlere entegresi hakkında genel bilgi edinildi

ve uygulaması yapıldı. Devre simülasyonu programlarının kullanımı ve simülasyonun

yapımı öğrenildi. Projeye ek bütçe olması açısından başvurulan diğer burslar ve

mühendislik tasarımı dersi tez dosyasının hazırlanması sayesinde makale yazımı

hakkında deneyim edinildi.
İleride bu çalışmanın bir bütçe kısıtı olmadığı durumlarda daha gelişmiş

algoritmalar ile daha düşük gecikme değerlerine sahip ve daha yüksek verimli evirici

tasarımı yapılabilir.

Bu çalışma günlük hayatta kullanılan ve şebeke geriliminde çalışan basit rezistif

yüklere yedek güç sağlamak ve bu gücü maksimum verimlilikte elde etmek için

yapılmıştır. Yapılan evirici devresinin çıkışına bir trafo eklenildiği durumda bu cihaz

şebeke elektriğinin olmadığı veya düzensiz olduğu her yerde kullanılabilir.

### 7. KAYNAKLAR

[1]. T. Paraskova, “World Energy Demand Jumped Above Pre-COVID Levels In 2021”,
OilPrice, | Web | [Online]. | (https://oilprice.com/Energy/Energy-General/World-Energy-
Demand-Jumped-Above-Pre-COVID-Levels-In-2021.html), Erişim tarihi: 1 Ocak 2025.

[2]. Dünya Enerji Konseyi Türk Milli Komitesi, “2021 Küresel Enerji Raporu Özeti”, Web [Online]. (https://www.dunyaenerji.org.tr/wp-content/uploads/2021/04/2021-Kuresel-Enerji-Raporu-Ozeti.pdf), Erişim tarihi: 1 Ocak 2025.

[3]. A. Namin, E. Chaidee, T. Sriprom, and P. Bencha, “Performance of Inductive Wireless Power Transfer Between Using Pure Sine Wave and Square Wave Inverters”, 2018 IEEE Transportation Electrification Conference and Expo, Asia-Pacific (ITEC Asia-Pacific), Bangkok, Thailand, 2018, pp. 1-5.

[4]. A. H. Eltom, and A. Demirbas, “Motor system energy efficiency in the nylon industry: A comparison of PWM and square wave inverters”, IEEE International Electric Machines and Drives Conference (IEMDC), Miami, FL, USA, 2009, pp. 508-513.

[5]. S. N. Dirim, “Adaptif Kontrol Sistemleri ve Gıda Endüstrisindeki Bazı Uygulamaları”, Akademik Gıda, Vol. 8, No. 3, 2010, pp. 43-46.

[6]. A. Bawdaka, ve İ. Kaya, “DC Motor Sürücüsü İçin Model Öngörülü Denetleyici Tasarımı”, DÜMF Mühendislik Dergisi, Vol. 10, No. 3, 2019, pp. 899-910.

[7]. B. K. A, V. S. G. K, J. F. S, and R. H, “Advanced control strategies for Servo motors: Analysis of PID, FUZZY-PID and MPC with cuk converter integration”, International Conference on Energy, Materials and Communication Engineering (ICEMCE), Madurai, India, 2023, pp. 1-6.

[8]. R. Menak, ve N. Tan, “H-∞ Karma Hassasiyet Problemi İçin Tasarlanan Kontrolörün Robust Kararlılık ve Performans Analizi”, Fırat Üniversitesi Uzay ve Savunma Teknolojileri Dergisi, Vol. 1, No. 1, 2022, pp. 121-126.

[9]. C. Knospe, “PID control”, IEEE Control Systems Magazine, Vol. 26, No. 1, Feb. 2006, pp. 30-31.

[10]. E. Eröz, and E. Tanyıldızı, “Güncel Metasezgisel Optimizasyon Algoritmalarının Performans Karşılaştırılması”, International Conference on Artificial Intelligence and Data Processing (IDAP), Malatya, Turkey, 2018, pp. 1-16.

[11]. Y. Liu, A. As’arry, M. K. Hassan, A. A. Hairuddin, and H. A. Mohamad, “Review of the grey wolf optimization algorithm: variants and applications”, Neural Computing and Applications, Vol. 36, No. 1, 2024, pp. 1-23.

[12]. N. Mittal, U. Singh, and B. S. Sohi, “Modified Grey Wolf Optimizer for Global Engineering Optimization”, Applied Computational Intelligence and Soft Computing, Vol.
2016, | Art. | ID | 7950348, | pp. | 1-16.

EKLER

EK-1. IEEE Etik Kuralları (Türkçe) ve IEEE Code of Ethics (İngilizce)

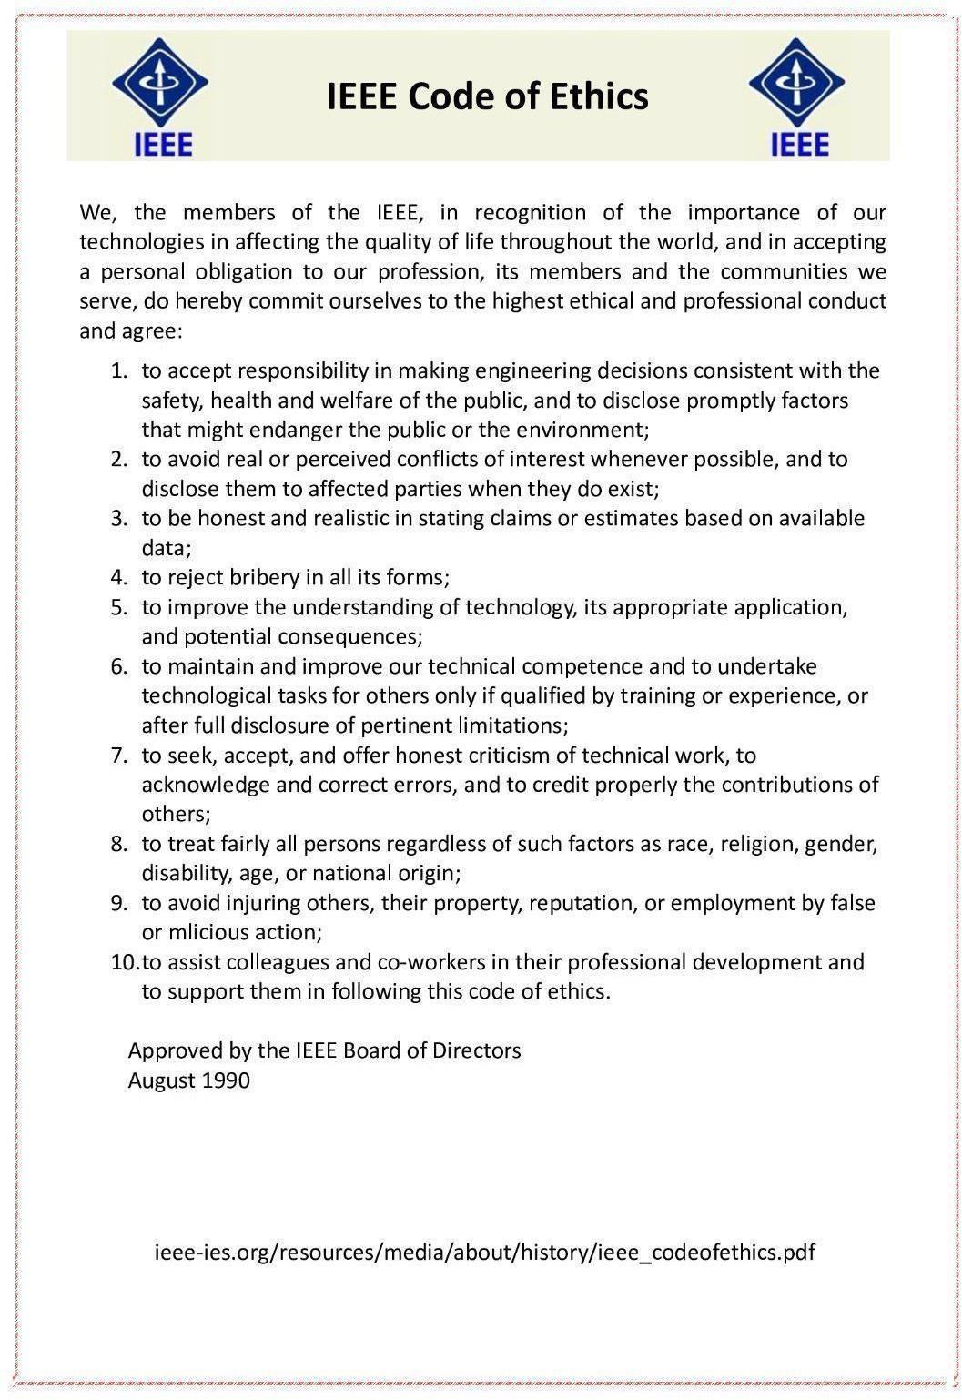
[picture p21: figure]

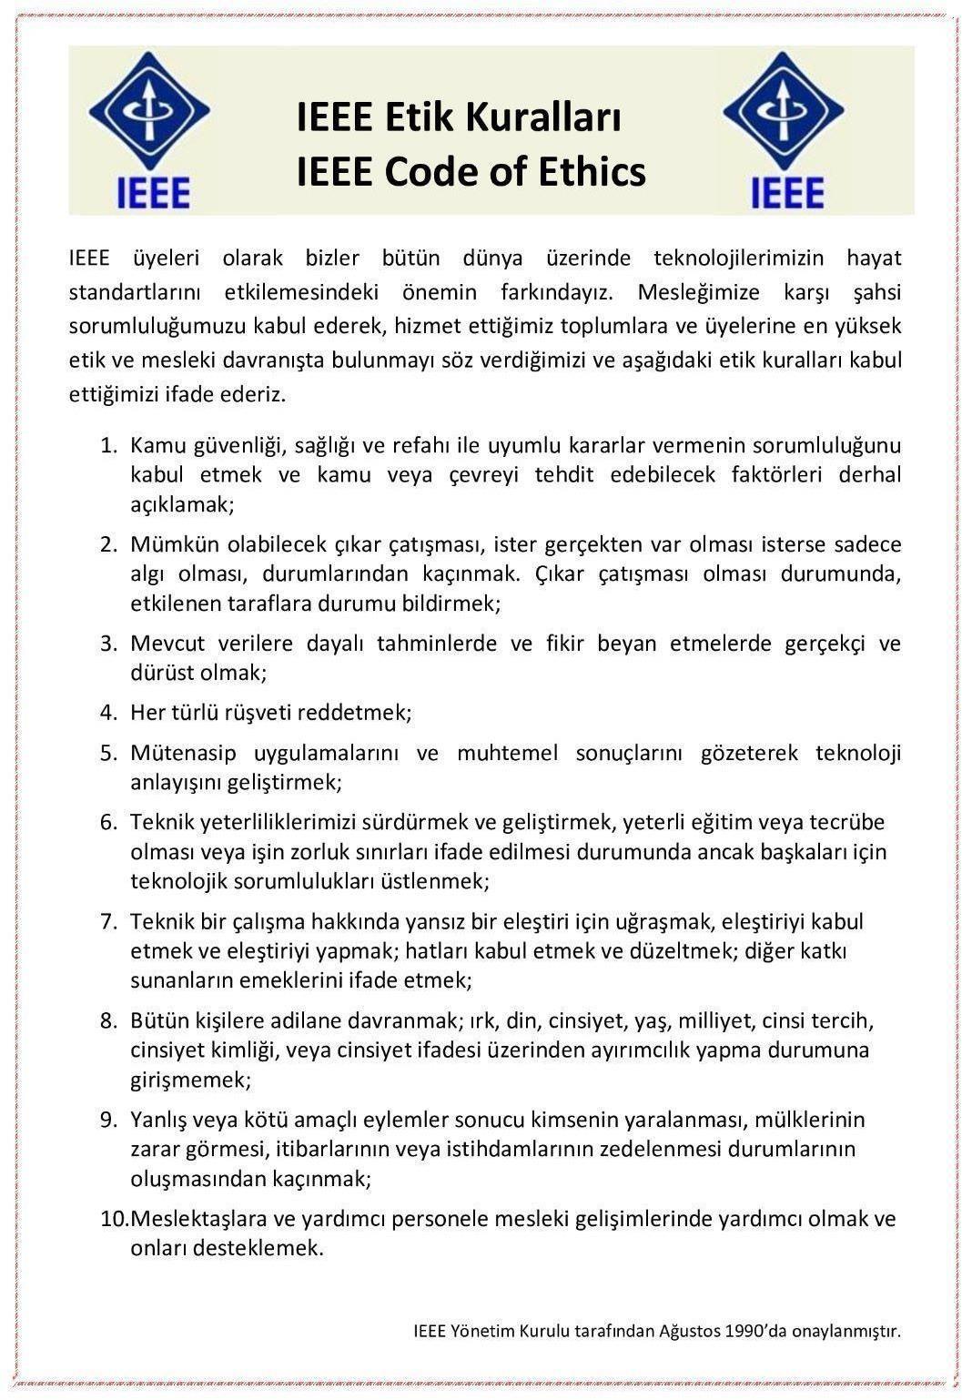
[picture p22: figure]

EK-2. Kısıtlar Formu

MÜHENDİSLİK TASARIMI veBİTİRMEPROJESİ KISITLAR FORMU

Kısıtlar | Açıklamalar
Tasarım Kısıtlamaları | Cihazın belirlenen sürede vereceği enerjiyi sağlayabilmesi gerekli. Çalışırken şebeke gerilimi ile çalışabileceği için herhangi bir güvenlik sorunu oluşturmamalı.
Prototip üretim kısıtlamaları | Prototipin üretim maliyetleri sınırlı olmalı ve bu sınıra göre hareket ederek minimum harcama ile maksimum performansa sahip parçalar seçilmelidir.
Uygulama kısıtlamaları | Cihaz içerisindeki bataryaların ve devrelerin yeterli soğutmasının yapılabilmesi için havalandırmanın her koşulda iyi yapılabilmesi gereklidir.
Toplumsal etki ve kısıtlamalar | Cihaz tamamlandığında çıkışına bir trafo bağlanarak istenilen herhangi bir yerde şebeke elektriği kullanılabilir taşınabilir yapısı sayesinde her yere götürülebilir durumda bir cihaz olacaktır. Cihazın toplumsal bir kısıtı olmayacaktır.
Sağlık kısıtlamaları | Sistemle doğrudan etkileşimde bulunan çalışanlar için sağlık ve güvenlik önlemleri alınmalıdır. Kullanılan maddelerin sağlık etkileri dikkate alınmalıdır.
Çevresel etki ve kısıtlamaları | Cihazın güvenli ve uzun ömürlü kullanımı için metal yüzeylerin ve elektronik devrelerin nemden korunması önemlidir. Bu nedenle cihaz, kuru ve uygun çevresel koşullarda kullanılmalıdır. Aksi takdirde paslanma ve diğer kimyasal reaksiyonlar oluşabilir. Ayrıca, aşırı sıcaklık değişimlerinden ve doğrudan güneş ışığından kaçınılması, cihazın ömrünü uzatmaya katkı sağlar.
Güvenlik kısıtlamaları | Cihazın giriş ve çıkışında şebeke gerilimi olabileceği için elektrik çarpmalarını önleyebilmek adına topraklamalı prizler tercih edilmeli ayrıca aşırı yükleme ve kısa devre gibi durumlarda koruma sağlamak için uygun sigorta kullanılmalıdır.
Mali kısıtlamalar | Proje bütçesinin sınırlı olabileceği durumu göz önüne alındığında bakım ve işletme maliyetleri bu sınıra göre düzenlenmelidir.
Hukuksal kısıtlamalar | Cihaz imal edilirken istenilen standartlara uyulmadığı durumlarda kalitesiz ürün kullanımından dolayı müşteri şikayetleri gelebilir ayrıca harmonik bozulmalar sebebiyle enerji sağlayıcı firmalardan ceza veya yaptırımlar gelebilir. Bunlar dikkat edilmesi gereken hukuki kısıtlamalardır.

EK-3. Özgeçmiş

Mahmut TOPALOĞLU

26 Kasım 2001 tarihinde İstanbul’da doğmuştur. İlk ve orta öğrenimini Demirözü

Yatılı Bölge İlk ve Ortaokulunda tamamlamıştır. Lise öğrenimini Bayburt Milli İrade

Anadolu Lisesinde tamamladıktan sonra Fırat Üniversitesi Elektrik-Elektronik

Mühendisliği bölümünde ilk yılında ingilizce hazırlık eğitimini sonraki yılda lisans eğitiminin ilk yılını tamamladıktan sonra Karadeniz Teknik Üniversitesinde eğitimini

devam ettirmiştir. TESCOM Kesintisiz Güç Kaynakları firmasında ve Bayburt Enerji firmasında güç elektroniği üzerine stajlar yapmıştır. Karadeniz Teknik Üniversitesinde

4. Sınıf öğrencisi olarak eğitimine devam etmektedir.

EK-4. Disiplinler Arası Çalışma

Disiplinler Arası Çalışma | Açıklama
Öğrenci toplulukları ile yapılan çalışmalar ve/veya Bitirme projesi için sanayide yapılan işlemler | Bu kapsamda kabin montajı harici bir atölye ortamında Ahmet Topaloğlu ile beraber yapılmıştır.

EK-5. Mühendislik Tasarım Teslim Koşulları Formu

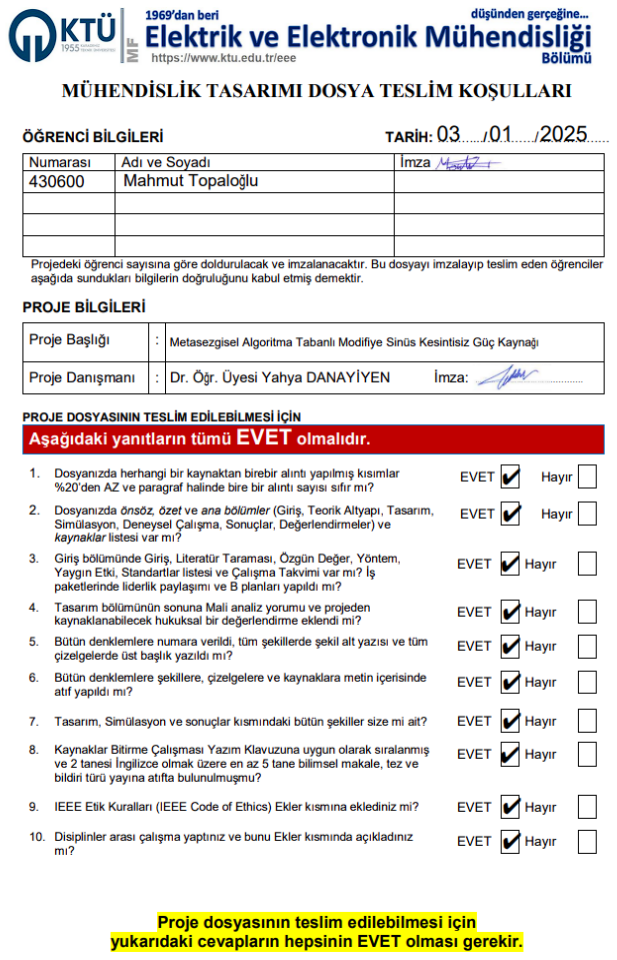
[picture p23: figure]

EK-6. Bitirme Projesi Teslim Koşulları Formu

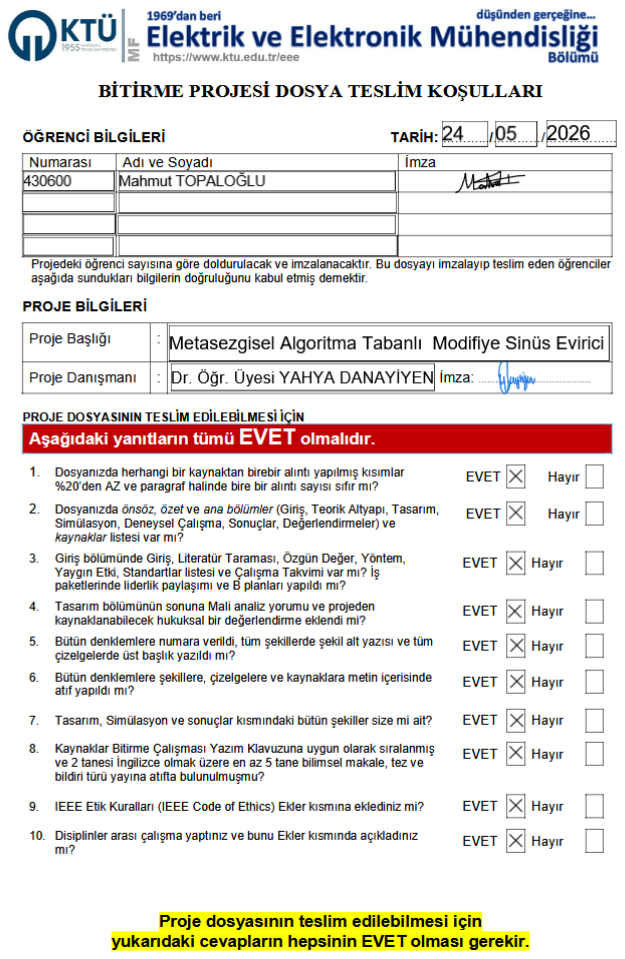
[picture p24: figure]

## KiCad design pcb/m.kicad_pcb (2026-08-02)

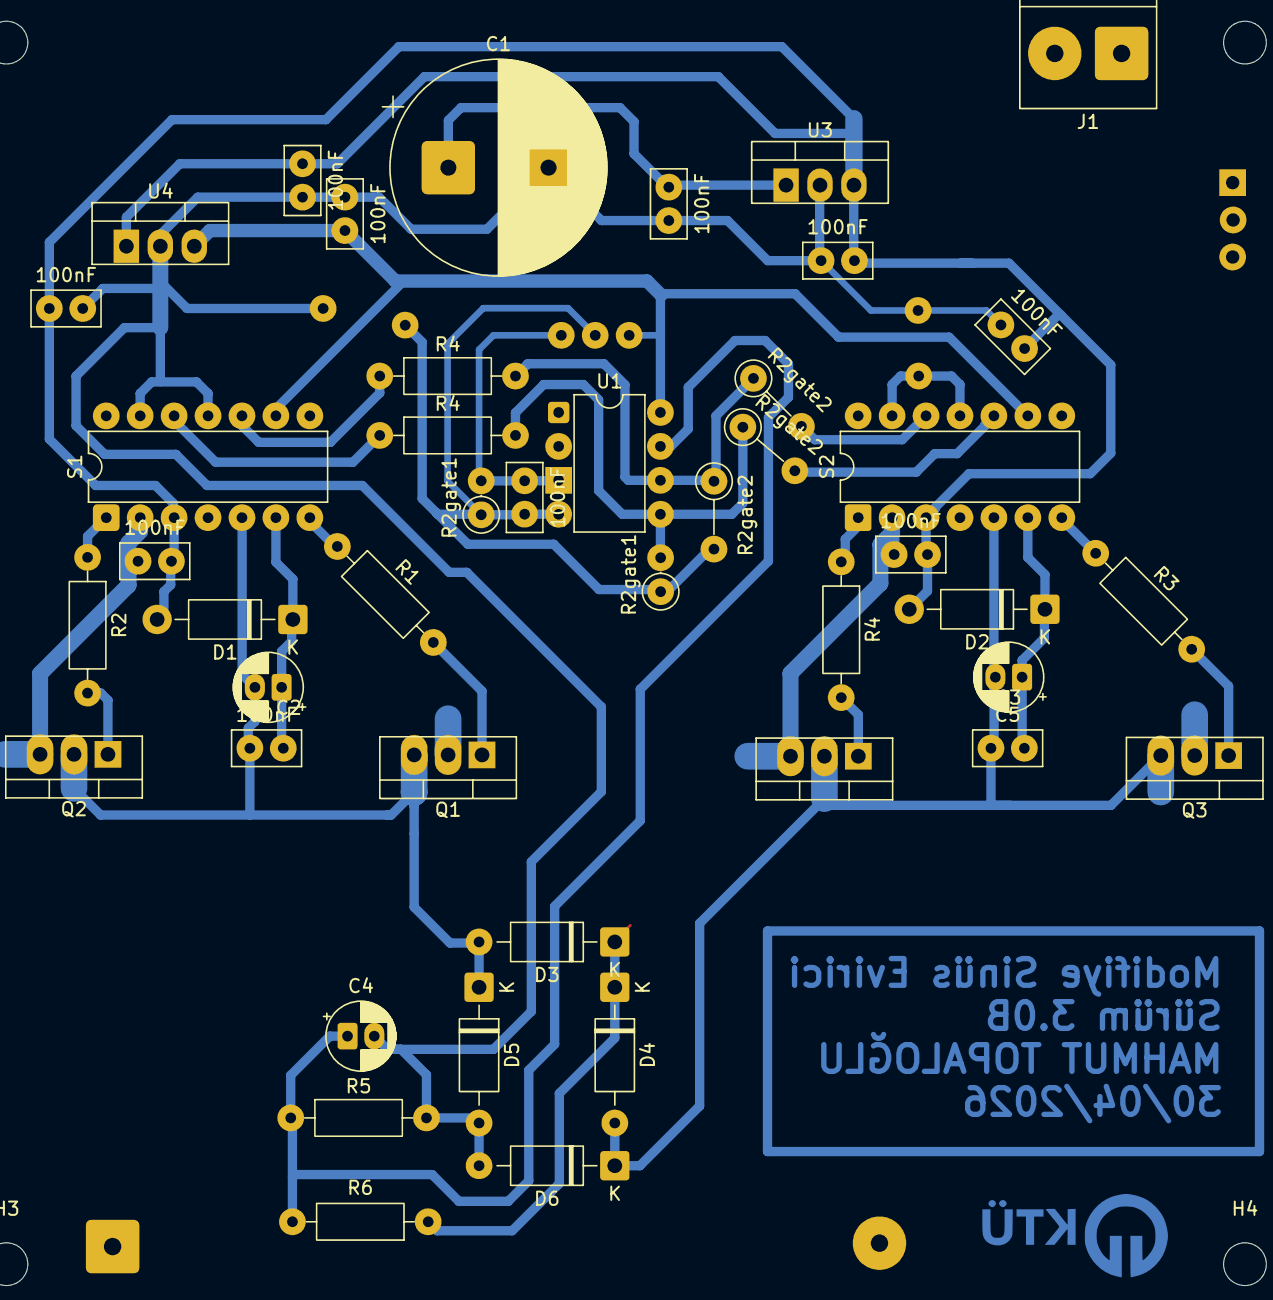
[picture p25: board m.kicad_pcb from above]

Board: 2 copper layers, 48 parts (0 on the bottom side), 21 nets.

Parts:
100nF, 100nF#2, 100nF#3, 100nF#4, 100nF#5, 100nF#6, 100nF#7, 100nF#8, 100nF#9, 100nF#10: C; C_Disc_D5.0mm_W2.5mm_P2.50mm
C1: 2.2mF; CP_Radial_D16.0mm_P7.50mm
C2, C3: 47uF; CP_Radial_D5.0mm_P2.00mm
C4: 10uF; CP_Radial_D5.0mm_P2.00mm
C5: C; C_Disc_D5.0mm_W2.5mm_P2.50mm
D1, D2, D3, D4, D5, D6: UF4007; D_DO-41_SOD81_P10.16mm_Horizontal
H1, H2, H3, H4: MountingHole; MountingHole_3.2mm_M3
J1: Batarya; TerminalBlock_Phoenix_PT-1,5-2-5.0-H_1x02_P5.00mm_Horizontal
Q1, Q2, Q3, Q4: IRLZ44N; TO-220-3_Vertical
R1, R2, R3, R4: 22R; R_Axial_DIN0207_L6.3mm_D2.5mm_P10.16mm_Horizontal
R2gate1: 100K; R_Axial_DIN0207_L6.3mm_D2.5mm_P2.54mm_Vertical
R2gate1#2: 10K; R_Axial_DIN0207_L6.3mm_D2.5mm_P2.54mm_Vertical
R2gate2, R2gate2#2, R2gate2#3: 220R; R_Axial_DIN0207_L6.3mm_D2.5mm_P5.08mm_Vertical
R4#2, R4#3: 220R; R_Axial_DIN0207_L6.3mm_D2.5mm_P10.16mm_Horizontal
R5: 4.7K; R_Axial_DIN0207_L6.3mm_D2.5mm_P10.16mm_Horizontal
R6: 22K; R_Axial_DIN0207_L6.3mm_D2.5mm_P10.16mm_Horizontal
S1, S2: IR2110; DIP-14_W7.62mm
U1: ATtiny85V-10P; DIP-8_W7.62mm
U3: LM7812_TO220; TO-220-3_Vertical
U4: LM7805_TO220; TO-220-3_Vertical

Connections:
/5V: 100nF#3.2, S1.9 (VDD), S2.9 (VDD), U1.8 (VCC), U4.3 (VO)
/12V: 100nF.1, 100nF#2.1, 100nF#6.2, 100nF#7.2, 100nF#9.2, 100nF#10.2, D1.2 (A), D2.2 (A), S1.3 (VCC), S2.3 (VCC), U3.3 (VO), U4.1 (VI)
/GND: 100nF.2, 100nF#2.2, 100nF#3.1, 100nF#4.2, 100nF#6.1, 100nF#7.1, 100nF#8.2, 100nF#9.1, 100nF#10.1, C1.2, C4.2, D5.2 (A), D6.2 (A), J1.1, Q2.3 (S), Q4.3 (S), R2gate1.1, R2gate1#2.1, R2gate2#3.2, R5.2, S1.2 (COM), S1.11 (SD), S1.13 (VSS), S2.2 (COM), S2.11 (SD), S2.13 (VSS), U1.4 (GND), U3.2 (GND), U4.2 (GND)
/Guc: 100nF#4.1, C1.1, J1.2, Q1.2 (D), Q3.2 (D), U3.1 (VI)
/L: 100nF#5.1, C2.2, D3.2 (A), D5.1 (K), Q1.3 (S), Q2.2 (D), S1.5 (VS)
/N: C3.2, D4.2 (A), D6.1 (K), Q3.3 (S), Q4.2 (D), S2.5 (VS)
/Sinyal1: R2gate1#2.2, R2gate2#2.1, R2gate2#2.2, R4#2.1, R4#2.2, S1.12 (LIN), S2.10 (HIN), U1.5 (AREF/PB0)
/Sinyal2: R2gate2.1, R2gate2.2, R2gate2#3.1, R4#3.1, R4#3.2, S1.10 (HIN), S2.12 (LIN), U1.6 (PB1)
unnamed: 100nF#5.2, C2.1, D1.1 (K), S1.6 (VB)
unnamed: C3.1, D2.1 (K), S2.6 (VB)
unnamed: D3.1 (K), D4.1 (K), R6.1
unnamed: Q1.1 (G), R1.2
unnamed: Q2.1 (G), R2.2
unnamed: Q3.1 (G), R3.2
unnamed: Q4.1 (G), R4.2
unnamed: R1.1, S1.7 (HO)
unnamed: R2.1, S1.1 (LO)
unnamed: R3.1, S2.7 (HO)
unnamed: R4.1, S2.1 (LO)
unnamed: C4.1, R5.1, R6.2, U1.7 (PB2)
unnamed: 100nF#8.1, R2gate1.2, U1.3 (XTAL2/PB4)

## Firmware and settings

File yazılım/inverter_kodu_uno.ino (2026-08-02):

#include <LiquidCrystal.h>

// --- ARDUINO UNO 50Hz TAM PROFESYONEL INVERTOR (TIMER1 + I2C LCD) ---

#include <Wire.h>
#include <LiquidCrystal_I2C.h>

// Ekran adresi genellikle 0x27 veya 0x3F olur. 16 sütun, 2 satır.
LiquidCrystal_I2C lcd(0x27, 16, 2); 

const int kanal_A = 9;    // Pozitif yarım dalga 
const int kanal_B = 10;   // Negatif yarım dalga 
const int sensorPin = A1; // Geri besleme
const int potPin = A2;    // Potansiyometre

// PI Katsayıları
float Kp = 0.06; 
float Ki = 1.9;  

long aktif_sure_us = 2270; 
volatile uint16_t aktif_sure_ticks = 4540; 
int eski_hata = 0; 
volatile bool pozitif_yari_dalga = true;

// Ekranı titretmemek için zamanlayıcı değişkeni
unsigned long son_ekran_guncelleme = 0;

void setup() {
  pinMode(kanal_A, OUTPUT);
  pinMode(kanal_B, OUTPUT);
  digitalWrite(kanal_A, LOW);
  digitalWrite(kanal_B, LOW);

  // --- LCD BAŞLATMA ---
  lcd.init();
  lcd.backlight();
  lcd.setCursor(0, 0);
  lcd.print("Mod.Sin. Evirici");
  lcd.setCursor(0, 1);
  lcd.print("***** KTU *****");
  delay(1500);
  lcd.clear();

  // =========================================================
  // TIMER 1 AYARLARI (50.00 Hz İÇİN)
  // =========================================================
  cli(); 
  TCCR1A = 0; 
  TCCR1B = 0;
  TCNT1  = 0; 
  TCCR1B |= (1 << WGM12); 
  TCCR1B |= (1 << CS11);  
  OCR1A = 19999; 
  TIMSK1 |= (1 << OCIE1A);
  sei(); 
  // =========================================================
}

// -----------------------------------------------------------
// 1. KESME: ZAMANLAYICI A (10ms Döngüsü)
// -----------------------------------------------------------
ISR(TIMER1_COMPA_vect) {
  if (aktif_sure_ticks > 0) {
    if (pozitif_yari_dalga) {
      digitalWrite(kanal_A, HIGH); 
    } else {
      digitalWrite(kanal_B, HIGH); 
    }
    OCR1B = aktif_sure_ticks; 
    TIFR1 |= (1 << OCF1B);
    TIMSK1 |= (1 << OCIE1B);
  }
  pozitif_yari_dalga = !pozitif_yari_dalga;
}

// -----------------------------------------------------------
// 2. KESME: ZAMANLAYICI B (Kapatma)
// -----------------------------------------------------------
ISR(TIMER1_COMPB_vect) {
  digitalWrite(kanal_A, LOW);
  digitalWrite(kanal_B, LOW);
  TIMSK1 &= ~(1 << OCIE1B);
}

// -----------------------------------------------------------
// ANA DÖNGÜ
// -----------------------------------------------------------
void loop() {
  // 1. POT OKUMA VE HEDEF BELİRLEME
  int potVal = analogRead(potPin);
  
  // PI algoritması için olan ham hedef (290 - 570)
  int dinamik_setpoint = map(potVal, 0, 1023, 245, 522);

  // 2. EKRAN GÜNCELLEME (Saniyede 4 kez)
  if (millis() - son_ekran_guncelleme > 250) {
    // Ekranda göstermek için pot değerini 12.0 ile 18.0 arasına çeviriyoruz.
    // Önce 120 ile 180 arasına çevirip 10'a bölüyoruz ki ondalıklı (float) veri elde edelim.
    float ekran_voltaji = map(potVal, 0, 1023, 120, 180) / 10.0;

    lcd.setCursor(0, 0);
    lcd.print("Cikis Voltaj:");
    lcd.setCursor(0, 1);
    lcd.print(ekran_voltaji, 1); // 1 ondalık hane yazdır (Örn: 14.5)
    lcd.print(" V   ");          // Sondaki boşluklar eski yazıları temizlemek için
    
    son_ekran_guncelleme = millis();
  }

  // 3. PI HESAPLAMA VE ÇIKIŞI DÜZENLEME
  long total = 0;
  for(int i = 0; i < 5; i++) { 
    total += analogRead(sensorPin); 
  }
  int okunan_deger = total / 5;

  int hata = dinamik_setpoint - okunan_deger;
  float degisim = (hata * Ki) + ((hata - eski_hata) * Kp);
  aktif_sure_us = aktif_sure_us + degisim;
  eski_hata = hata; 

  if (aktif_sure_us > 6500) aktif_sure_us = 6500; 
  if (aktif_sure_us < 0) aktif_sure_us = 0;       

  // Değeri donanıma gönder
  cli();
  aktif_sure_ticks = aktif_sure_us * 2;
  sei();

  delay(5); // Ufak bir nefes alma arası
}
